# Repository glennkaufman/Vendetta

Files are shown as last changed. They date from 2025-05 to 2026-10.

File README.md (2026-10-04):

# Vendetta Toolhead Assembly Guide

Welcome to the official assembly guide for the **Vendetta Toolhead**—designed to deliver fully functional ability to use your V400 with Box Turtle!
Fully fuctional toolhead cutting, filament sensors, lighting, Canbus or USB, CPAP or stock cooling.

---

## 🔧 Tools & Materials Required

* Original V400 effector for base parts
* Soldering iron (for inserts)
* [BOM Hardware](assembly/BOM.md)
* Your full set of Vendetta STLs

---

## 📦 Bill of Materials

*All STL files are organized in subfolders within `/models/STLs/`*
### [*Hardware BOM*](assembly/BOM.md)

### Main Body

* [`main_body_front_enable_supports.stl`](models/STLs/main_body_front/main_body_front_enable_supports.stl)
* [`main_body_rear.stl`](models/STLs/main_body_rear/main_body_rear.stl)

### Cutter Arm

* [`cutter_arm.stl`](models/STLs/cutter_arm/cutter_arm.stl)
* [`cutter_arm_button.stl`](models/STLs/cutter_arm/cutter_arm_button.stl)
* [`cutter_arm_button_v2.stl`](models/STLs/cutter_arm/cutter_arm_button_v2.stl)
* [`cutter_arm_mount_cutter_pin.stl`](models/STLs/cutter_arm/cutter_arm_mount_cutter_pin.stl)
* [`cutter_arm_mount_cutter_pin_long.stl`](models/STLs/cutter_arm/cutter_arm_mount_cutter_pin_long.stl)

### Shroud

* [`shroud.stl`](models/STLs/shroud/shroud.stl)
* [`shroud_fan.stl`](models/STLs/shroud/shroud_fan.stl)
* [`shroud_logo.stl`](models/STLs/shroud/shroud_logo.stl)

### CPAP Adapter

* [`cpap_upper.stl`](models/STLs/cpap/cpap_upper.stl)
* [`cpap_mid_left.stl`](models/STLs/cpap/cpap_mid_left.stl)
* [`cpap_mid_right.stl`](models/STLs/cpap/cpap_mid_right.stl)
* [`cpap_low_left.stl`](models/STLs/cpap/cpap_low_left.stl)
* [`cpap_low_right.stl`](models/STLs/cpap/cpap_low_right.stl)

### Idler

* [`idler_with_supports.stl`](models/STLs/idler/idler_with_supports.stl)

### Fan Duct Covers

* [`Fan_Duct_Covers.stl`](models/STLs/fan_duct_covers/Fan_Duct_Covers.stl)

### Misc Add-ons

* [`rear_pillar_brush_indexer.stl`](models/STLs/misc_addons/rear_pillar_brush_indexer.stl)

---

## 🧠 Assembly Overview

The Vendetta Toolhead is a modular, high-performance design tailored for Box Turtle Automated Filament Changer.

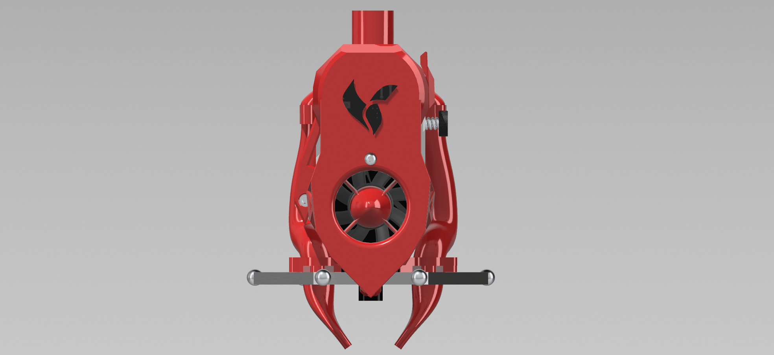
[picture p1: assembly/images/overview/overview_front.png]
Overview Front

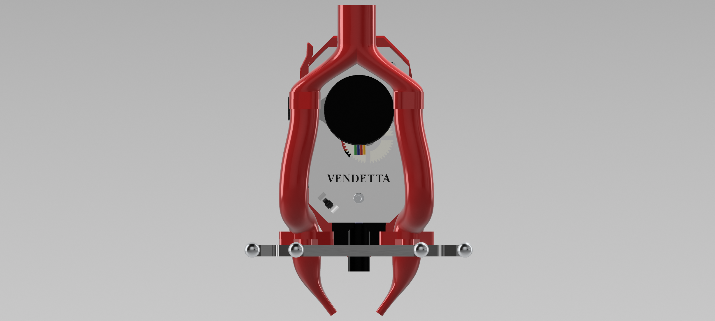
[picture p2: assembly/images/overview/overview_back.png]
Overview Back

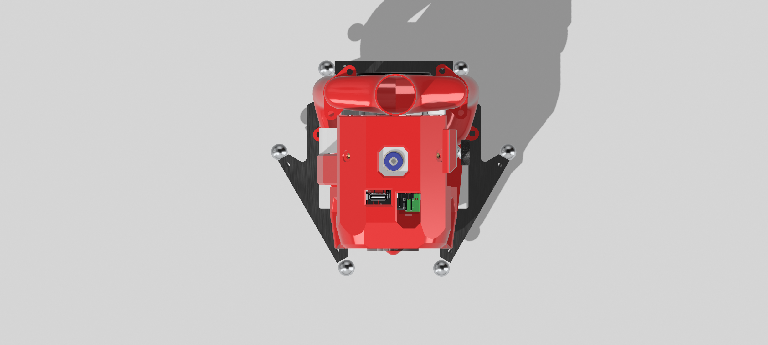
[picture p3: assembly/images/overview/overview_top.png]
Overview Perspective


---

## 🧱 Main Body (Front)

Secures to the effector via the heatsink. Houses cutting blade, filament sensor, and EBB42.

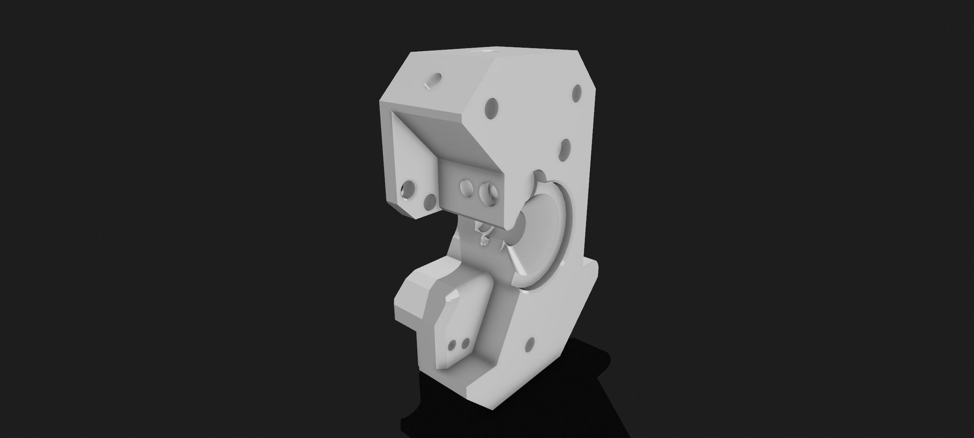
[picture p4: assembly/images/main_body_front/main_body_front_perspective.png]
Main Body Perspective


---

## 🧱 Main Body (Rear)

Secures to the main body front. Mounts the stock stepper for the extruder.

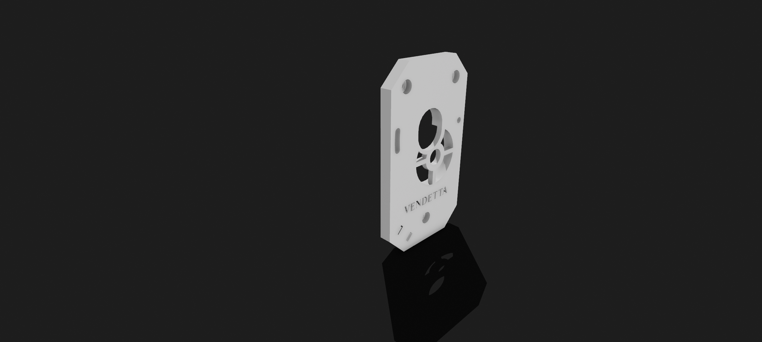
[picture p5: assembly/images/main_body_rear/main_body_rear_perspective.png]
Main Body Perspective


---

## ⚙️ Cutter Arm

Used for filament cutting. Options for cutting your own chisel blades or purchasing bambu cutter blades.

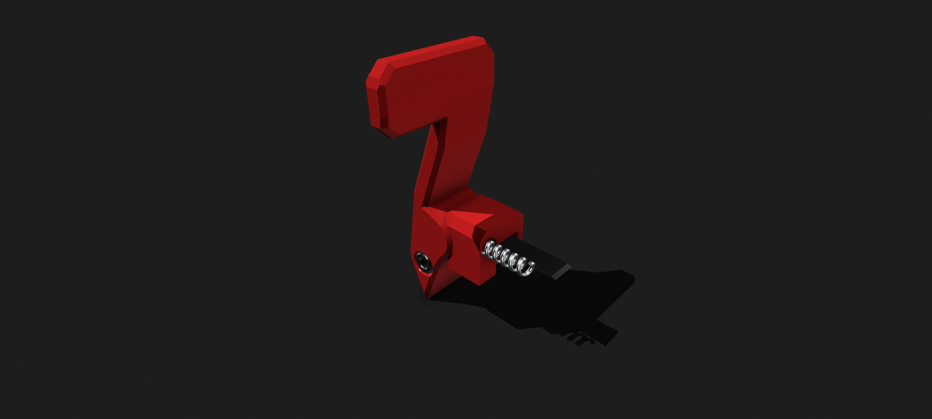
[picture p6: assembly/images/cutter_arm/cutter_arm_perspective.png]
Cutter Arm Perspective


---

## 🌬️ Shroud

Ability to integrate Knomiv2 or strictly run heatbreak fan with nose cone.

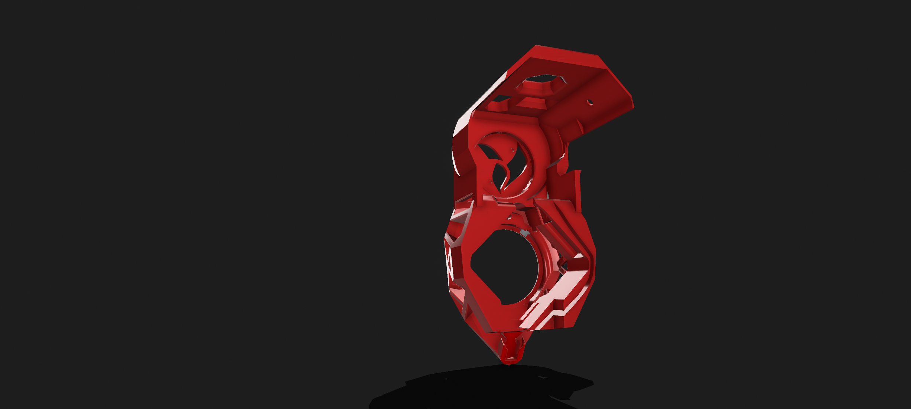
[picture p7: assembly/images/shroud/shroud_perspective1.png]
Shroud Perspective1

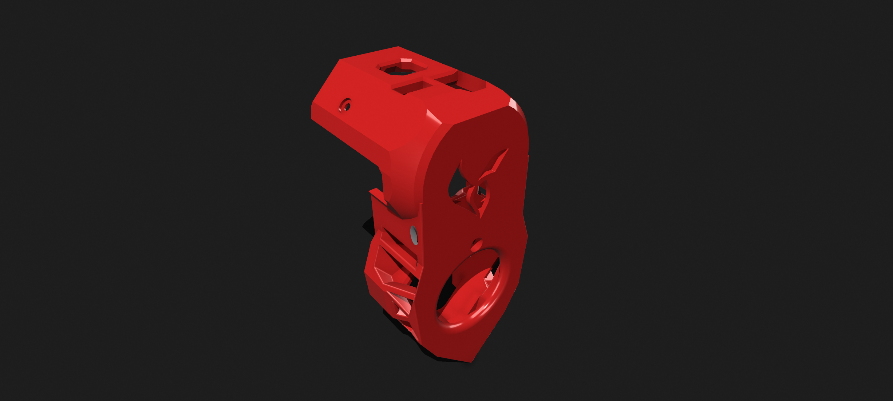
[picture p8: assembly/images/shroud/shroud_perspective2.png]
Shroud Perspective2


---

## 🫁 CPAP Adapter

Optional component for integrating an external CPAP high-flow fan.

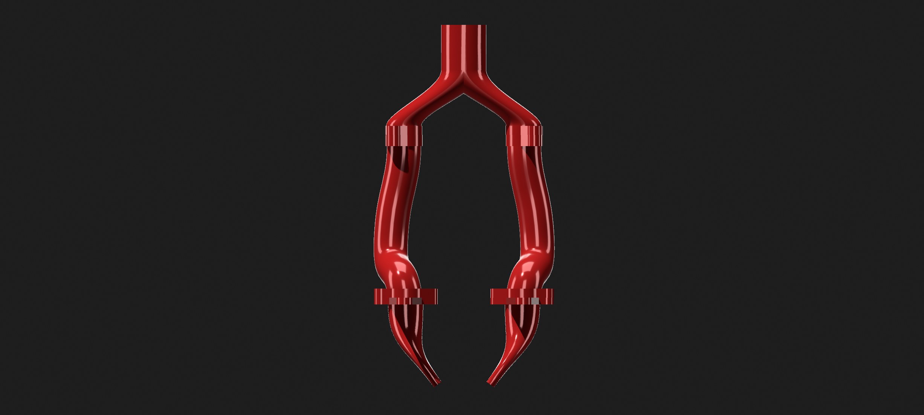
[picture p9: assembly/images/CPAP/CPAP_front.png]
CPAP Front

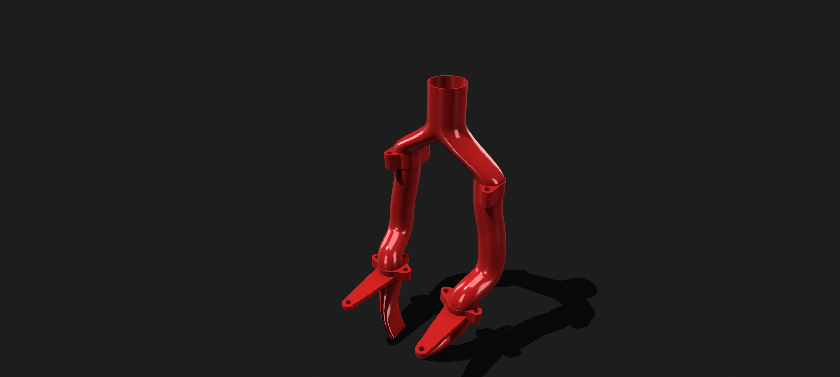
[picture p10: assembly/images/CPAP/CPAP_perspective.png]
CPAP Perspective


---

## 🛞 Idler

Extruder tension arm for filament path.

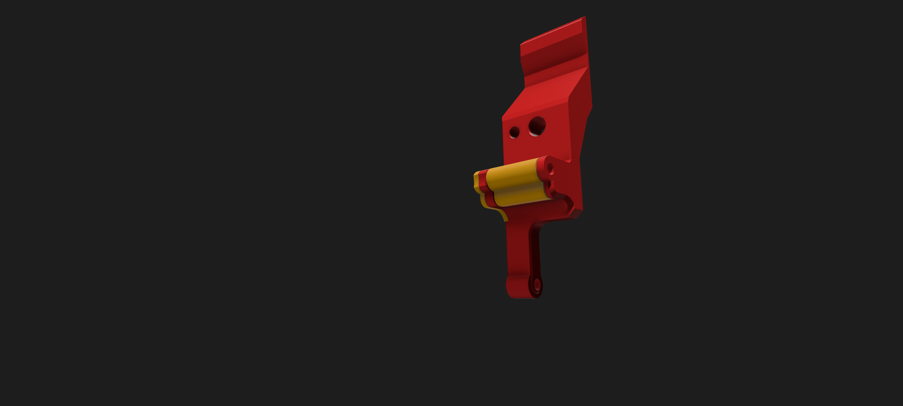
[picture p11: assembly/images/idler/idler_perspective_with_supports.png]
Idler Perspective


---

## ✅ Final Assembly Checklist

* [ ] All bolts torqued
* [ ] Threadlocker applied where needed
* [ ] Fan and CPAP tested
* [ ] Belt alignment verified
* [ ] Hotend wired and verified

---

## Firmware Configuration

All firmware configuration files are organized under the [`firmware/config_files/`](firmware/config_files) directory, sorted by hardware and use case. These settings are tailored specifically for the Vendetta tool head and its supporting components.

- **Box Turtle Settings**  
  Configuration optimized for the Box Turtle mod—ensuring smooth integration and reliable performance on supported machines. (`AFC*.cfg` files in `firmware/config_files/`)

- **Octopus Pro v1.1 (H723)**  
  Dedicated configuration files for the BigTreeTech Octopus Pro v1.1 (H723) board. These files are pre-tuned for compatibility and performance. (`firmware/config_files/octopus_pro_and_vendetta_toolhead/`)

- **Vendetta Tool Head**  
  Custom settings specifically for the Vendetta tool head. Includes pin mappings, thermal tuning, and motion tweaks to get the most out of your hardware.

> **Note:** The sample configs are for reference only. They were tested with Klipper v0.13.x (my printer runs v0.13.0-786 as of Oct 2026). Pressure advance, input shaper, and the AFC bowden length (`afc_bowden_length`) and `tool_stn` / `tool_stn_unload` values are specific to my printer and must be tuned for yours.

---

## [📹 Assembly Videos](assembly/Videos.md)

*In Production to YouTube — [YouTube](https://youtube.com/playlist?list=PLWgEg1ho19xm_LMkO39CTWQdfH5PHcdP_&si=Ss74mZV-d5u0i4Tc)*

---

## 🧠 Notes

* For firmware configurations, PID tuning, and offsets, refer to your printer’s mainboard documentation.
* Contributions welcome. Submit pull requests or file issues as needed.

---

## 🔗 License

MIT License. Build, remix, and share—with attribution.

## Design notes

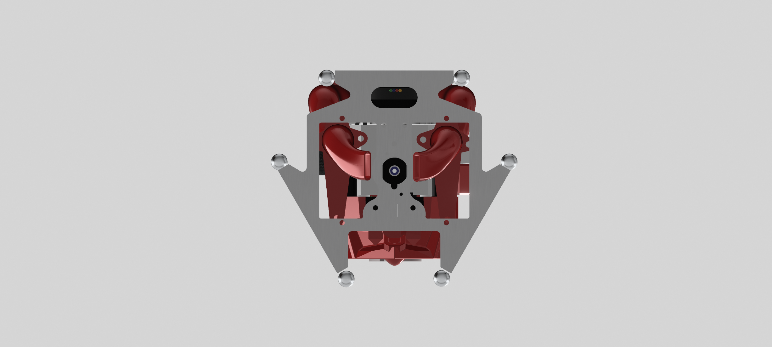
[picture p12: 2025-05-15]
assembly/images/overview/overview_bottom.png

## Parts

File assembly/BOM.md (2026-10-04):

# Bill of Materials (BOM)

| | | BOM | | | | |
|:---|:---|:---|:---|:---|:---|:---|
| Number | Description | Quantity | Link | Price | REQ/OPT | |
| 1 | BIGTREETECH EBB42 CAN Bus with MAX31865 Adapter Board | 1 | [Link](https://amzn.to/46TVVoy) | $ 23.99 | REQ | |
| 2 | BIGTREETECH KNOMI 2 | 1 | [Link](https://amzn.to/48OWNxd) | $ 31.99 | OPT | Not required if using cone in Vendetta hotend |
| 3 | GDSTIME 2Pcs 40mm Fan 24V, Dual Ball Bearing 40x40x10mm | 1 | [Link](https://amzn.to/42QUrdJ) | $ 10.39 | OPT | Not required if using original heatsink fan |
| 4 | BIGTREETECH Octopus Pro v1.1 (H723) Control Board 32Bit Silent Motherboard | 1 | [Link](https://amzn.to/4h46FW6) | $ 43.19 | OPT | Not required if using original control board |
| 5 | BIGTREETECH Universal Turbo Kit 24V Brushless Centrifugal Air Blower | 1 | [Link](https://amzn.to/3VUjiJy) | $ 60.79 | OPT | Not required if using stock parts cooling fans |
| 6 | MR63ZZ Miniature Deep Groove Ball Bearings,Pre-Lubricated & High RPM Support - - 3x6x2.5mm | 3 | [Link](https://amzn.to/4mRJxLK) | $ 10.99 | REQ | |
| 7 | Bamboo lab 3PCS Filament Cutter Blade | 1 | [Link](https://amzn.to/4nCCKXj) | $ 9.99  | REQ | |
| 8 | M3 Heat Inserts M3 x D5 x L4 Brass Threaded Inserts | 14 | [Link](https://amzn.to/4mXmqj5) | $ 9.99  | REQ | |
| 9 | WS2812B RGB LED Rings 7 Bits 5050 Lamp Light with Integrated Drivers | 1 | [Link](https://amzn.to/4o2e1vs) | $ 15.99 | REQ | |
| 10 | WS2812B Addressable 5050 Smart RGB LED Pixel Light on Black Heat Sink PCB Board 5V DC | 1 | [Link](https://amzn.to/432MHVP) | $ 14.99 | REQ | |
| 11 | Capricorn Teflon Tube PTFE Bowden Tubing 1.75mm Filament, Low Friction | 1 | [Link](https://amzn.to/48lsAWq) | $ 11.49 | REQ | |
| 12 | BMG Extruder kit w MR85 bearings | 1 | [Link](https://amzn.to/4o8dMPC) | $ 14.99 | OPT | Optional, but includes MR85 bearings. No need to purchase separate bearings below |
| 13 | MR85-2RS Deep Groove Ball Bearings 5mm Inner Dia 8mm OD 2.5mm Bore Double Sealed Chrome Steel Z2 | 2 | [Link](https://amzn.to/4oak5Cm) | $ 8.19  | REQ | Required if using stock V400 extruder gears |
| 14 | Omron D2HW-C201H | 1 | [Link](https://mou.sr/3ILoFrw) | $ 2.35  | REQ | |
| 15 | M3x25 BHCS | 1 | | | | |
| 16 | M3x20 SHCS | 2 | | | | |
| 17 | M3x16 SHCS | 2 | | | | Can use stock hardware |
| 18 | M3x8 BHCS | 4 | | | | |
| 19 | M3x6 BHCS | 9 | | | | |
| 20 | ECAS Bowden Collet | 1 | | | | |
| 21 | 4mmODx20 .5 Spring | 1 | | | | |

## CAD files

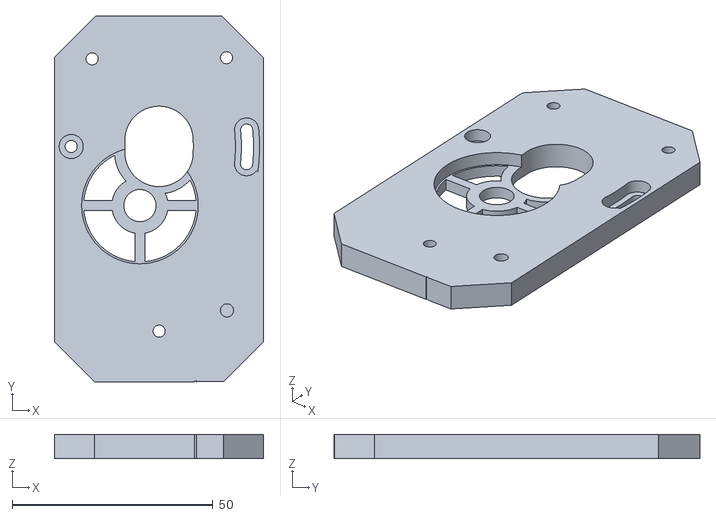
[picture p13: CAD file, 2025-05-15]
models/STLs/main_body_rear/main_body_rear.stl
52.0 x 91.0 x 6.00

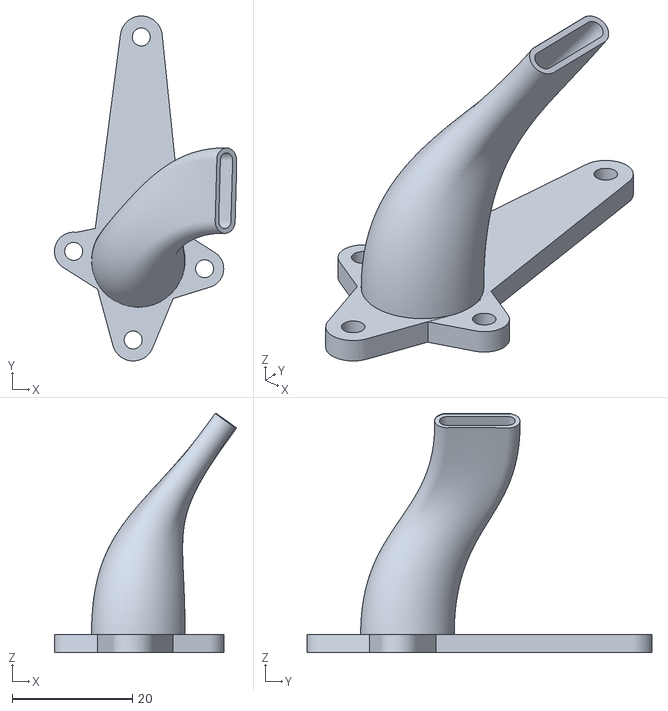
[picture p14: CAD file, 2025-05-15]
models/STLs/cpap/cpap_low_left.stl
30.3 x 57.5 x 39.9

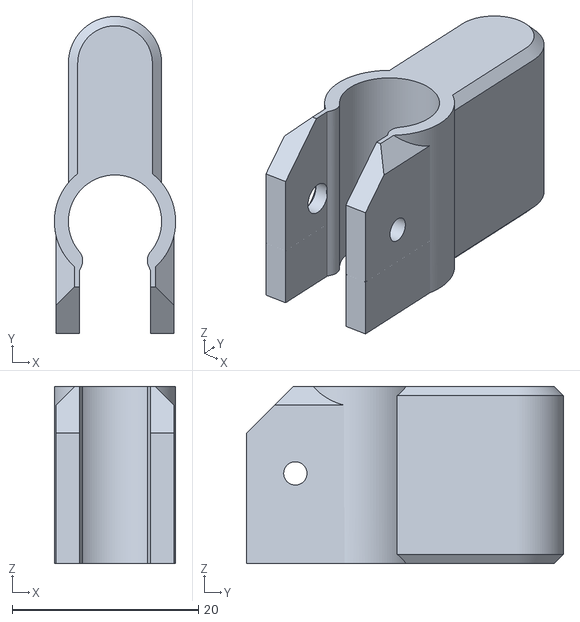
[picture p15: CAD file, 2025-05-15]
models/STLs/cutter_arm/cutter_arm_mount_cutter_pin_long.stl
13.0 x 34.0 x 19.0

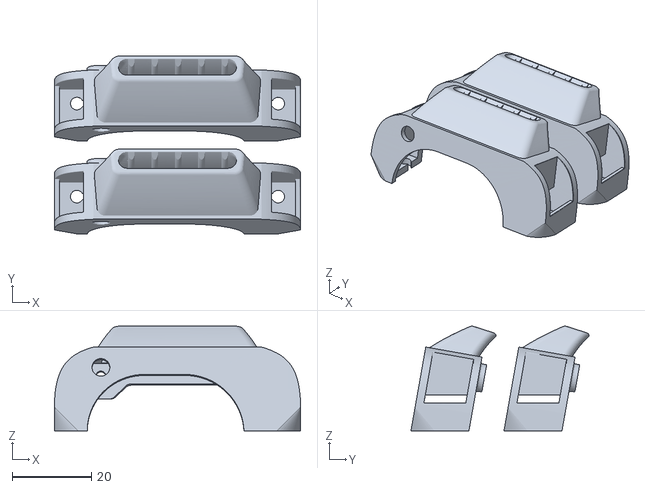
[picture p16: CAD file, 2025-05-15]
models/STLs/fan_duct_covers/Fan_Duct_Covers.stl
62.0 x 44.9 x 26.4

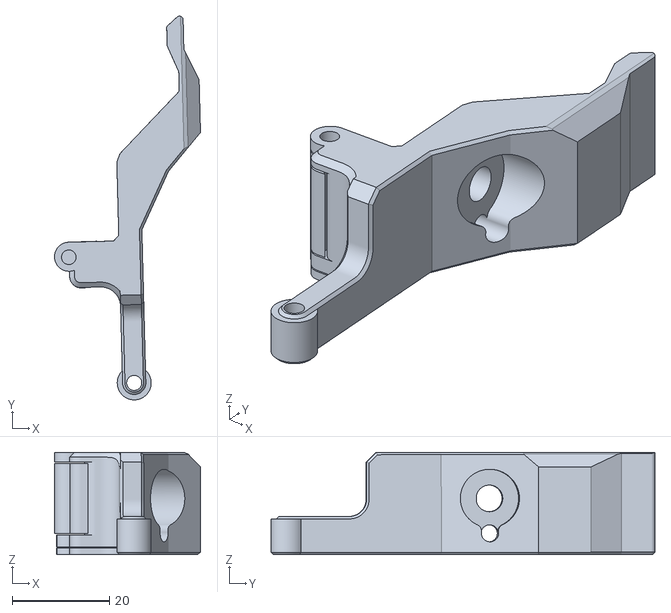
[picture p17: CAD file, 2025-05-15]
models/STLs/idler/idler_with_supports.stl
30.1 x 79.1 x 21.1

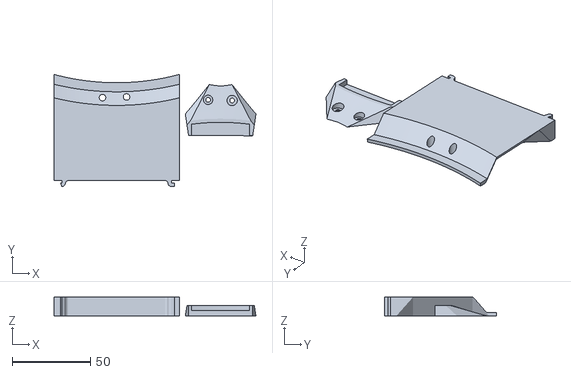
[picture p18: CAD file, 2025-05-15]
models/STLs/misc_addons/rear_pillar_brush_indexer.stl
129.1 x 71.7 x 11.9

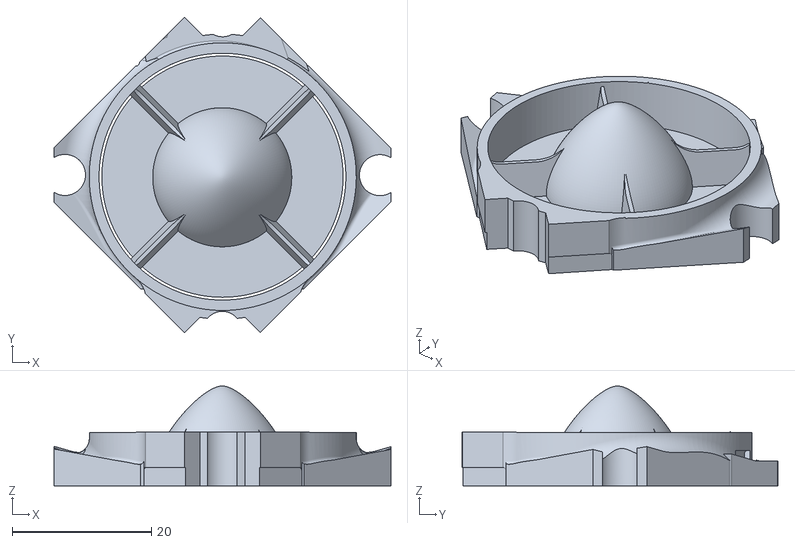
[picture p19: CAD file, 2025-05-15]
models/STLs/shroud/shroud_fan.stl
48.5 x 45.4 x 14.4

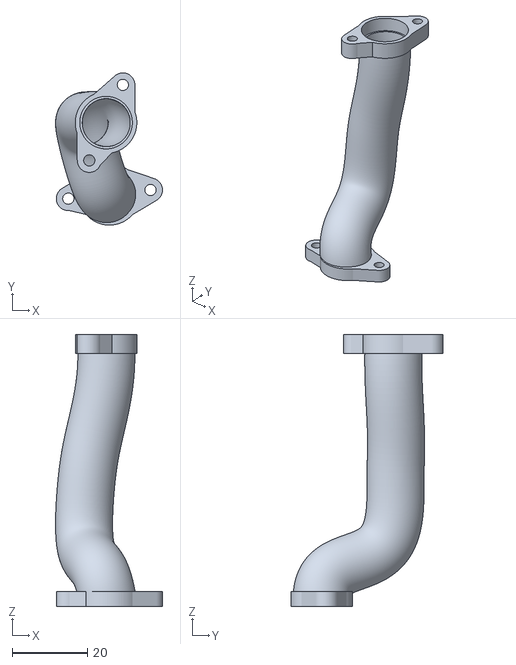
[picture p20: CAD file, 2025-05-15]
models/STLs/cpap/cpap_mid_left.stl
28.5 x 40.5 x 72.4

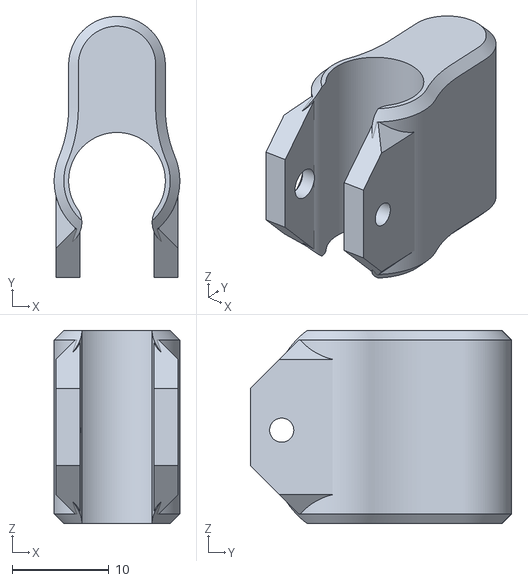
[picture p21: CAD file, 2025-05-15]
models/STLs/cutter_arm/cutter_arm_mount_cutter_pin.stl
13.0 x 27.0 x 20.0

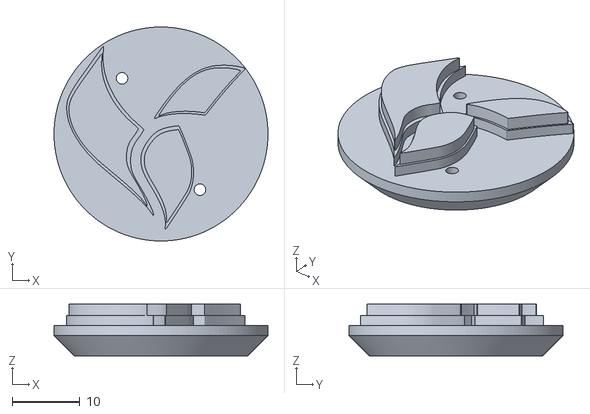
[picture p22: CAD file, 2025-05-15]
models/STLs/shroud/shroud_logo.stl
31.5 x 31.5 x 7.64

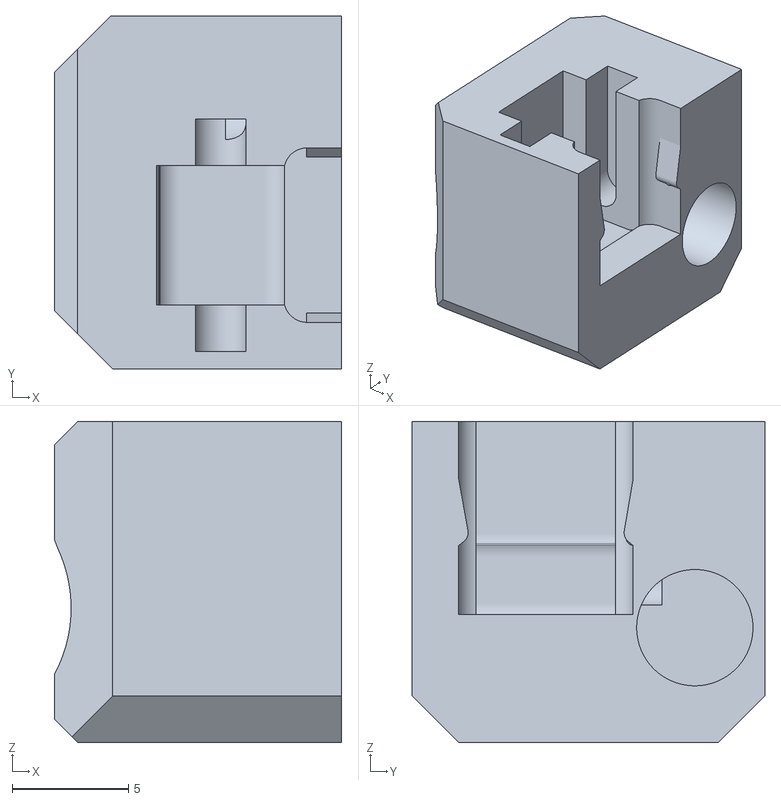
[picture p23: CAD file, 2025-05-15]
models/STLs/cutter_arm/cutter_arm_button.stl
12.3 x 15.2 x 13.8

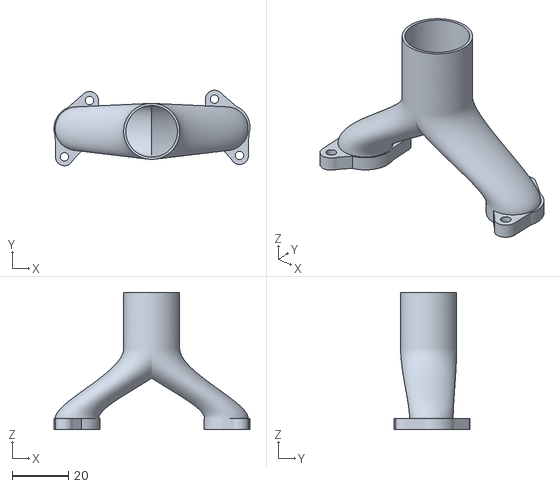
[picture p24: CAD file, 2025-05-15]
models/STLs/cpap/cpap_upper.stl
69.9 x 27.0 x 49.0

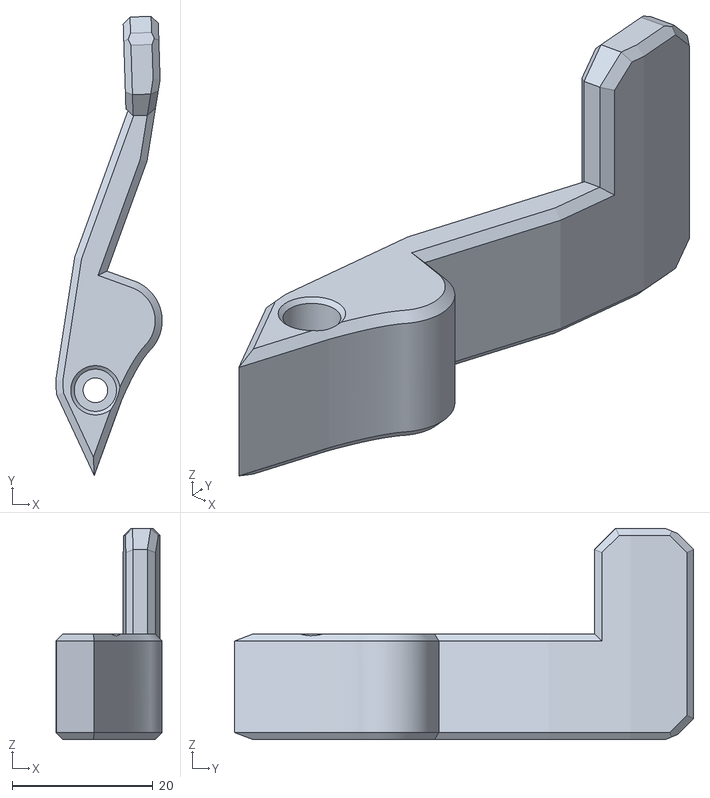
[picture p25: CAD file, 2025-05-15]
models/STLs/cutter_arm/cutter_arm.stl
15.1 x 65.3 x 30.0

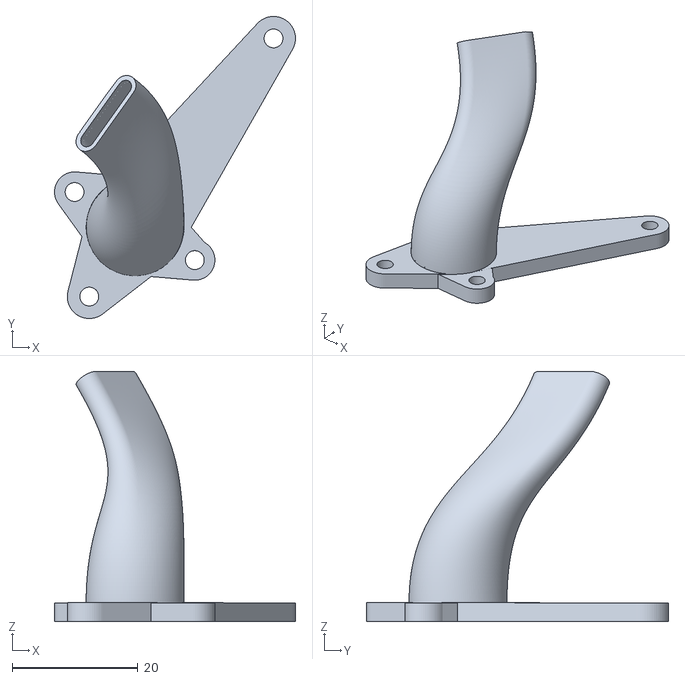
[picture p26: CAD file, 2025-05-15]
models/STLs/cpap/cpap_low_right.stl
38.4 x 48.1 x 39.9

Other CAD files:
models/STLs/main_body_front/main_body_front_enable_supports.3mf
models/STLs/cpap/cpap_mid_right.stl
models/STLs/cutter_arm/cutter_arm_button_v2.stl
models/STLs/main_body_front/main_body_front_enable_supports.stl

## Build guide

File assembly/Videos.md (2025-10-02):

## 📹 Assembly Videos

### Vendetta Parts Print (https://www.youtube.com/watch?v=nWyVzOlXdS0)  
*Vendetta Parts Print* — 6:20

### Vendetta - Supports Removal (https://www.youtube.com/watch?v=ZrVvXxl8cqo)  
*Vendetta - Supports Removal* — 8:28

### Vendetta - Heatset Inserts Installation (https://www.youtube.com/watch?v=ajmu_imUpPU)  
*Vendetta - Heatset Inserts Installation* — 9:12

### Vendetta - Parts Assembly (https://www.youtube.com/watch?v=J0I8exbBQgA)
*Vendetta - Parts Assembly* — 1:19:37

---

### 🎥 **Full Playlist:** [Vendetta Toolhead Assembly on YouTube](https://www.youtube.com/playlist?list=PLWgEg1ho19xm_LMkO39CTWQdfH5PHcdP_)

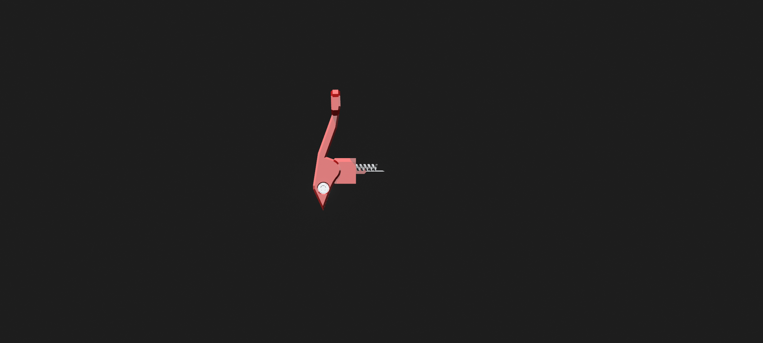
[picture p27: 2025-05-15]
assembly/images/cutter_arm/cutter_arm_front.png

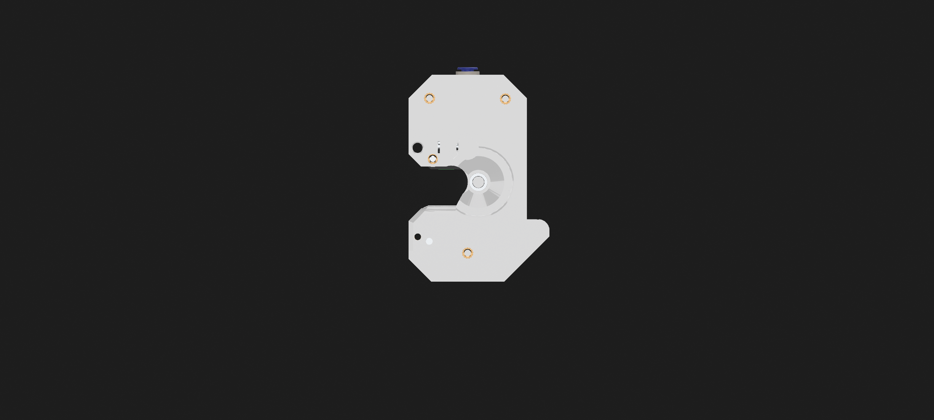
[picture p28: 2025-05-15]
assembly/images/main_body_front/main_body_front_back.png

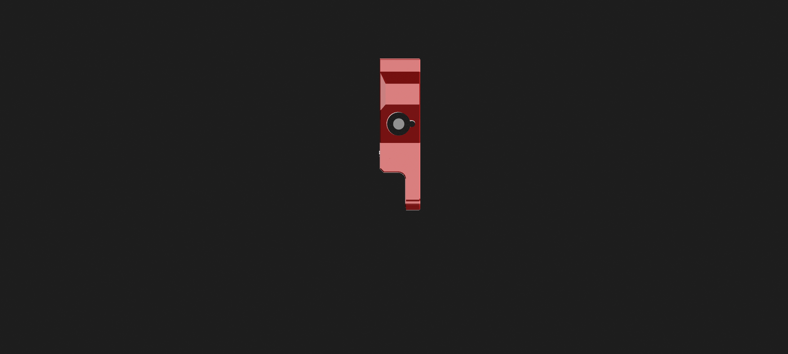
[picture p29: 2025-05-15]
assembly/images/idler/idler_right.png

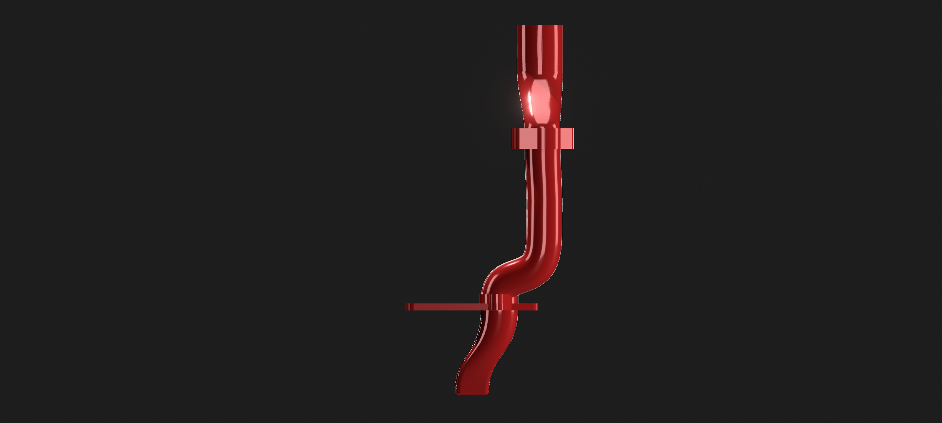
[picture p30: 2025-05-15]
assembly/images/CPAP/CPAP_right.png

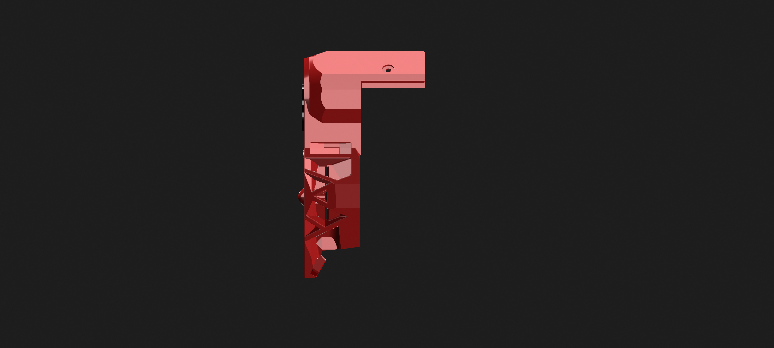
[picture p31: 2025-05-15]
assembly/images/shroud/shroud_right.png

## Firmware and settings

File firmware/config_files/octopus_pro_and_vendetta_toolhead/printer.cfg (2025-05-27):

#   _____             __ _                       _   _                
#  / ____|           / _(_)                     | | (_)                
# | |     ___  _ __ | |_ _  __ _ _   _ _ __ __ _| |_ _  ___  _ __  ___ 
# | |    / _ \| '_ \|  _| |/ _` | | | | '__/ _` | __| |/ _ \| '_ \/ __|
# | |___| (_) | | | | | | | (_| | |_| | | | (_| | |_| | (_) | | | \__ \
#  \_____\___/|_| |_|_| |_|\__, |\__,_|_|  \__,_|\__|_|\___/|_| |_|___/
#                           __/ |                                      
#                          |___/    
#
# Klipper Configurations - Flsun V400


########################################
# Firmware Settings
########################################

# This file contains common pin mappings for the BigTreeTech Octopus
# Pro v1.1 board.

# Important! Do not use this config with an Octopus Pro v1.0 board nor
# non-Pro board.

# To use this config, during "make menuconfig", select "Enable
# low-level configuration options", select the STM32H723
# micro-controller, select a "128KiB bootloader", and select a "25Mhz
# crystal".

# See docs/Config_Reference.md for a description of parameters.

########################################
# Editable Settings
########################################

# Notes: Some settings can be enabled or disabled by removing or adding the '#' symbol
#
# PID (pid_Kp, pid_Ki, pid_Kd) --> [extruder] and [heater_bed] sections
# E-Steps Extruder (rotation_distance) --> [extruder] section --> <rotation_distance> = <full_steps_per_rotation> * <microsteps> / <steps_per_mm>
# Pressure Advance (pressure_advance) --> [extruder] section -- See: https://www.klipper3d.org/Pressure_Advance.html
# Firmware Retraction --> [firmware_retraction] section -- Requires "Klipper Settings Plugin" for Cura -- See: https://github.com/jjgraphix/KlipperSettingsPlugin

########################################
# Included Files
########################################

#[include macros.cfg]    #Enable to use macros file
#[include timelapse.cfg]  #Enable if you want to use Timelapse
#[include btt-hbb.cfg]
#[include led-effects.cfg]
#[include vendetta_led.cfg]
#[include AFC/*.cfg]
#[include BTKS_Macros.cfg]

########################################
# Printer Settings
########################################

[printer]
kinematics: delta
max_velocity: 600
max_accel: 3500
minimum_cruise_ratio: 0.5
square_corner_velocity: 6
max_z_velocity: 300
max_z_accel: 1500
minimum_z_position: -5
print_radius: 152
#delta_radius: 161.75

########################################
# MCU Settings
########################################

[mcu]        #Select serial or canbus
#serial: 
#canbus_uuid: 
#canbus_interface: can0
[mcu EBBCan]  #Select serial or canbus
#serial: 
#canbus_uuid: 
#canbus_interface: can0

[temperature_sensor Motherboard]
sensor_type: temperature_mcu
min_temp: 20
max_temp: 80

[temperature_sensor EBB]
sensor_type: temperature_mcu
sensor_mcu: EBBCan
min_temp: 20
max_temp: 80

[temperature_sensor RaspberryPi]
sensor_type: temperature_host
min_temp: 10
max_temp: 80 

########################################
# X Stepper Motor & Driver Settings
########################################

# Stepper a
[stepper_a]
step_pin: PF13
dir_pin: PF12
enable_pin: !PF14
microsteps: 64
rotation_distance: 40
endstop_pin: PG6 #STOP0
homing_speed: 50
homing_retract_dist: 5.0
homing_retract_speed: 10
#angle: 210
#position_endstop: 415.0
#arm_length = 345.0

[tmc2209 stepper_a]
uart_pin: PC4
diag_pin: PG6 #STOP0
run_current: 1.500
sense_resistor = .110
interpolate: false
stealthchop_threshold: 0

#[autotune_tmc stepper_a]  # Enable if Klipper TMC Autotune is used
#motor: flsun-v400-42
#tuning_goal: performance

[endstop_phase stepper_a]
endstop_align_zero: False

########################################
# Y Stepper Motor & Driver Settings
########################################

# Stepper b
[stepper_b]
step_pin: PG0
dir_pin: PG1
enable_pin: !PF15
microsteps: 64
rotation_distance: 40
endstop_pin: PG9
#angle: 330

[tmc2209 stepper_b]
uart_pin: PD11
diag_pin: PG9
run_current: 1.500
sense_resistor = .110
interpolate: false
stealthchop_threshold: 0

#[autotune_tmc stepper_b]  # Enable if Klipper TMC Autotune is used
#motor: flsun-v400-42
#tuning_goal: performance

[endstop_phase stepper_b]
endstop_align_zero: False

########################################
# Z Stepper Motor & Driver Settings
########################################

# Stepper c
[stepper_c]
step_pin: PF11
dir_pin: PG3
enable_pin: !PG5
microsteps: 64
rotation_distance: 40
endstop_pin: PG10
#angle: 90

[tmc2209 stepper_c]
uart_pin: PC6
diag_pin: PG10
run_current: 1.500
sense_resistor = .110
interpolate: false
stealthchop_threshold: 0

#[autotune_tmc stepper_c]  # Enable if Klipper TMC Autotune is used
#motor: flsun-v400-42
#tuning_goal: performance

[endstop_phase stepper_c]
endstop_align_zero: False 

########################################
# Extra Stepper Motor & Driver Settings
########################################

# Driver3
# The Octopus only has 4 heater outputs which leaves an extra stepper
# This can be used for a second Z stepper, dual_carriage, extruder co-stepper,
# or other accesory such as an MMU
#[stepper_]
#step_pin: PG4
#dir_pin: PC1
#enable_pin: !PA2
#endstop_pin: PG11
#...

########################################
# Extruder & Driver Settings
########################################
#SETTINGS BELOW ARE FOR VENDETTA TOOLHEAD

[extruder]
step_pin: EBBCan: PD0
dir_pin: !EBBCan: PD1
enable_pin: !EBBCan: PD2
microsteps: 16
rotation_distance: 4.500
nozzle_diameter: 0.400
filament_diameter: 1.750
max_extrude_cross_section: 50
max_extrude_only_distance: 1000
pressure_advance: 0.02
pressure_advance_smooth_time: 0.040
heater_pin: EBBCan: PB13
sensor_type: EPCOS 100K B57560G104F
sensor_pin: EBBCan: PA3
#control: pid_v
#pid_Kp=15.752
#pid_Ki=0.908
#pid_Kd=68.331
min_temp: 10
max_temp: 300

[tmc2209 extruder]
uart_pin: EBBCan: PA15
run_current: 0.8
sense_resistor = .110
interpolate: True
stealthchop_threshold: 999999

[heater_fan hotend_fan]
pin: EBBCan: PA0
heater: extruder
heater_temp: 50.0

# Driver4
#[extruder]
#step_pin: PF9
#dir_pin: !PF10
#enable_pin: !PG2
#heater_pin: PA0 # HE0
#sensor_pin:  PF4 # T0
#...

# Driver5
#[extruder1]
#step_pin: PC13
#dir_pin: PF0
#enable_pin: !PF1
#heater_pin: PA3 # HE1
#sensor_pin: PF5 # T1
#...

# Driver6
#[extruder2]
#step_pin: PE2
#dir_pin: PE3
#enable_pin: !PD4
#heater_pin: PB0 # HE2
#sensor_pin: PF6 # T2
#...

# Driver7
#[extruder3]
#step_pin: PE6
#dir_pin: PA14
#enable_pin: !PE0
#heater_pin: PB11 # HE3
#sensor_pin: PF7 # T3
#...

########################################
# Delta Calibration & Mesh Settings
########################################

[delta_calibrate]
radius: 148
horizontal_move_z: 25
speed: 50

[bed_mesh]
speed: 100
horizontal_move_z: 30
mesh_radius: 148
mesh_origin: 0,0
mesh_pps: 4,4
round_probe_count: 9
algorithm: bicubic
bicubic_tension: 0.1
move_check_distance: 5
zero_reference_position: 0,0
fade_start: 1
fade_end: 30 

########################################
# Temperature Controls
########################################

[verify_heater extruder]
max_error: 160
heating_gain: 1

[verify_heater heater_bed]
max_error: 120
heating_gain: 1

########################################
# Heating
########################################

[heater_bed]
heater_pin: PA1 #BED-OUT
sensor_pin: PF3 #TB
sensor_type: EPCOS 100K B57560G104F
min_temp: 10
max_temp: 120
#control = pid_v
#pid_kp = 64.044
#pid_ki = 3.812
#pid_kd = 268.984

########################################
# Firmware Retraction Settings
########################################

[firmware_retraction]
retract_length: 0.2
retract_speed: 50
unretract_extra_length: 0.00
unretract_speed: 50

########################################
# Input Shaper Settings
########################################

[adxl345]    #ADXL1345 ON VENDETTA TOOLHEAD
cs_pin: EBBCan: PB12
spi_software_sclk_pin: EBBCan: PB10
spi_software_mosi_pin: EBBCan: PB11
spi_software_miso_pin: EBBCan: PB2
axes_map: x,y,z

[input_shaper]
shaper_freq_x: 42.0
shaper_type_x = ei
shaper_freq_y: 56.2
shaper_type_y = 2hump_ei
damping_ratio_x: 0.183
damping_ratio_y: 0.171

[resonance_tester]
probe_points:0, 0, 200
accel_chip: adxl345
max_smoothing:0.5
min_freq: 5
max_freq: 133.33
accel_per_hz: 75
hz_per_sec: 1

[idle_timeout]
timeout: 10800

[save_variables]
filename: ~/printer_data/config/variables.cfg

[virtual_sdcard]
path: ~/printer_data/gcodes

[display_status]

[pause_resume]

[respond]

########################################
# LED Settings
########################################

[neopixel vendetta_leds]
pin: EBBCan:PD3
chain_count: 8
#   The number of Neopixel chips that are "daisy chained" to the
#   provided pin. 1-7 in the logo and 8 at the lower shroud for nozzle.
color_order: GRB
#   Set the pixel order required by the LED hardware. Options are GRB,
#   RGB, GRBW, or RGBW. The default is GRB.
initial_RED: 0
initial_GREEN: 0
initial_BLUE: 0
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

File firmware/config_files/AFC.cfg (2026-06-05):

[AFC]
VarFile: /home/glenn/printer_data/config/AFC/AFC.var   # Path to the variables file for AFC configuration.

#--=================================================================================-
#------- Speed ----------------------------------------------------------------------
#--=================================================================================-
long_moves_speed: 150           # mm/s. Default value is 150mm/s.
long_moves_accel: 250           # mm/s². Default value is 250mm/s².
short_moves_speed: 50           # mm/s. Default value is 50mm/s.
short_moves_accel: 300          # mm/s². Default value is 300mm/s².
short_move_dis: 10              # Move distance for failsafe moves. Default is 10mm.

#global_print_current: 0.6       # Uncomment to set stepper motors to a lower current while printing
                                # This value can also be set per stepper with print_current: 0.6
enable_sensors_in_gui: True     # Uncomment to show all sensor switches as filament sensors in mainsail/fluidd gui
                                # this can also be set at individual levels in your config file
default_material_temps: default: 235, PLA:210, PETG:235, ABS:235, ASA:235 # Default temperature to set extruder when loading/unloading lanes.
                                                  # Material needs to be either manually set or uses material from spoolman if extruder temp is not
                                                  # set in spoolman. Follow current format to add more
common_density_values: PLA:1.24, PETG:1.23, ABS:1.04, ASA:1.07 # Generic default density values.  Follow current format to add more
default_material_type: ASA     # Default material type to assign to a spool once loaded into a lane

load_to_hub: True               # Fast loads filament to hub when inserted, set to False to disable. This is a global setting and can be overridden at AFC_stepper
#moonraker_port: 7125            # Port to connect to when interacting with moonraker. Used when there are multiple moonraker/klipper instances on a single host

assisted_unload: True           # If True, the unload retract is assisted to prevent loose windings, especially on full spools. This can prevent loops from slipping off the spool. This is a global setting and can be overridden at the unit and stepper level.
#pause_when_bypass_active: True  # When True AFC pauses print when change tool is called and bypass is loaded
#unload_on_runout: True          # When True AFC will unload lane and then pause when runout is triggered and spool to swap to is not set(infinite spool)
#print_short_stats: True          # Set to true to print AFC_STATS in short form instead of wide form, printing short form is better for consoles that are small in width
#debug: True                     # Setting to True turns on more debugging to show on console

#--=================================================================================-
#------- TRSYNC Values --------------------------------------------------------------
#--=================================================================================-
#trsync_update: True           # Uncomment this value to update Klipper's trsync value automatically
#trsync_timeout: 0.05          # Uncomment this value if timeout needs to be greater than the default of 0.05
#trsync_single_timeout: 0.250  # Uncomment this value if single_timeout needs to be greater than the default of 0.250

#--=================================================================================-
#------- Pause/Resume ---------------------------------------------------------------
#--=================================================================================-
z_hop: 5                        # Height to move up before and after a tool change completes
resume_speed: 120               # Speed mm/s of resume move. Set to 0 to use gcode speed
resume_z_speed: 30              # Speed mm/s of resume move in Z. Set to 0 to use gcode speed
error_timeout: 36000            # Time in seconds to pause when an error is detected.
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

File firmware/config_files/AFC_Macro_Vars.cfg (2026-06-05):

[include macros/*.cfg]

#--=================================================================================-
#------- Global ---------------------------------------------------------------------
#--=================================================================================-
[gcode_macro _AFC_GLOBAL_VARS]
description: Global variables used in multiple macros
gcode: # Leave Empty

# Set this to match your AFC_stepper base naming in AFC_Hardware.cfg
variable_stepper_name             : 'lane'    # [AFC_stepper lane1] [AFC_stepper lane2]...

variable_travel_speed             : 200      # Speed mm/s
variable_z_travel_speed           : 50        # Speed mm/s
variable_accel                    : 2000      # Move accel for all macro moves
variable_disable_skew_correction  : False      # When True macros will disable and re-enable skew correction while performing kinematic actions, useful if you took your measurements before loading your skew profiles which may limit where the toolhead can go during print.
variable_verbose                  : 1         # Console Output for macros
                                              #  0 - None
                                              #  1 - Limited
                                              #  2 - All


#--=================================================================================-
#------- Cut -----------------------------------------------------------------------
#--=================================================================================-
[gcode_macro _AFC_CUT_TIP_VARS]
description: Toolhead tip cutting macro configuration variables
gcode: # Leave empty

# This should be the position of the toolhead where the cutter arm just
# lightly touches the depressor pin
variable_pin_loc_xy               : -100, 0    # x,y coordinates of depressor pin

# Accel during cut. This will overwrite the global accel for this macro. Set to 0 to use global accel
variable_cut_accel                : 0

# Direction to make the cut move (left, right, front, back)
variable_cut_direction            : "left"

# This distance is used to move toolhead to cut filament
# and to create a small safety distance that aids in generating momentum
variable_pin_park_dist            : 10.0       # Distance in mm

# Position of the toolhead when the cutter is fully compressed.
# Distance the toolhead needs to travel to compress the cutter arm.
# To calculate this distance start at the pin_loc_xy position and move
# your toolhead till the cutter arm is completely compressed. Take 0.5mm off this distance
# as a buffer. 
# Ex pin_loc_x : 9, 310  fully compressed at 0, 310 set cut_move_dist to 8.5
variable_cut_move_dist            : 52       # Distance in mm

# Speed related settings for tip cutting
# Note that if the cut speed is too fast, the steppers can lose steps.
# Therefore, for a cut:
# - We first make a fast move to accumulate some momentum and get the cut
#   blade to the initial contact with the filament
# - We then make a slow move for the actual cut to happen 
variable_cut_fast_move_speed      : 100        # Speed mm/s
variable_cut_slow_move_speed      : 40        # Speed mm/s
variable_evacuate_speed           : 150       # Speed mm/s
variable_cut_dwell_time           : 50        # Time to dwell at the cut point in ms
variable_cut_fast_move_fraction   : 0.90      # Fraction of the move that uses fast move 0.0 - 1.0
variable_extruder_move_speed      : 25        # Speed mm/s for all extruder movement

# If the toolhead returns to initial position after the cut is complete.
variable_restore_position         : False     # True = return to initial position, False = don't return

# Distance to retract prior to making the cut, this reduces wasted filament but might cause clog 
# if set too large and/or if there are gaps in the hotend assembly 
# *This must be less than the distance from the nozzle to the cutter
variable_retract_length           : 33

# This can help prevent clogging of some toolheads by doing a quick tip from to reduce stringing
variable_quick_tip_forming        : False

# Number of times to run the cut movement
variable_cut_count                : 2

# Retract length and speed after the cut so that the cutter can go back 
# into its origin position
variable_rip_length               : 1.0       # Distance in mm to retract to aid lever decompression (>= 0)
variable_rip_speed                : 3         # Speed mm/s

# Pushback of the remaining tip from the cold end into the hotend
# *Must be less then retract_length
variable_pushback_length          : 25        # Distance in mm
variable_pushback_dwell_time      : 20        # Time to dwell between the pushback

# Safety margin for fast vs slow travel. When traveling to the pin location
# we make a safer but longer move if we are closer to the pin than this
# specified margin. Usually setting these to the size of the toolhead
# (plus a small margin) should be good enough 
variable_safe_margin_xy           : 20, 20    # Approx toolhead width +5mm, height +5mm)

# Some printers may need a boost of power to complete the cut without skipping steps.
# One option is to increase the current for the steppers in printer.cfg. Another
# option is to use these variables to set a current that is only used during the
# cut motion. Different combinations of kinematics and cutter configurations engage
# different combinations of steppers for that motion.  Set the needed variables.
# The override is skipped if the current is 0.

# Enable if layer shifts occur when cutting
# variable_cut_current_stepper_x: 0
# variable_cut_current_dual_carriage: 0  # This is the value that is used to define the current for the dual carriage stepper (2nd x) for an IDEX printer during the cut.
# variable_cut_current_stepper_y: 0
# variable_cut_current_stepper_z: 0

# Change these to match the entries in printer.cfg if needed
# variable_conf_name_stepper_x: "tmc2209 stepper_x"
# variable_conf_name_dual_carriage: "tmc2209 dual_carriage"
# variable_conf_name_stepper_y: "tmc2209 stepper_y"
# variable_conf_name_stepper_z: "tmc2209 stepper_z"
# variable_awd: True

# Addon variables for cutter pin servo control
#variable_tool_servo_enable        : False
#variable_tool_servo_name          : "tool_cut"
#variable_tool_servo_angle_out     : 115
#variable_tool_servo_angle_in      : 0

#--=================================================================================-
#------- Poop ----------------------------------------------------------------------
#--=================================================================================-
[gcode_macro _AFC_POOP_VARS]
description: Poop macro configuration variables
gcode: # Leave empty


variable_purge_loc_xy             : -50, 139    # (x,y) Location of where to purge
variable_purge_spd                : 3       # Speed, in mm/s, of the purge.
variable_z_purge_move             : True      # Set to False to not move in Z during poop

# Speed, in mm/s to lift z after the purge is completed. Its a faster lift to keep it from 
# sticking to the toolhead
variable_fast_z                   : 400
variable_z_lift                   : 30        # Z height to raise above the final purge position after the purge is completed as part of the fast z move
                                              # example: If final poop height ends at 20mm this variable will raise Z to 30mm

# If the toolhead returns to initial position after the poop is complete.
variable_restore_position         : False     # True = return to initial position, False = don't return

# The z height of the nozzle at the purge position before purging. This allows any built up
# pressure to escape before the purge.

variable_purge_start              : 0.5

# Set the part cooling fan speed. Disabling can help prevent the nozzle from cooling down 
# and stimulate flow, Enabling it can prevent blobs from sticking together.
variable_part_cooling_fan         : True      # Run it at full speed
variable_part_cooling_fan_speed   : 0.4       # Speed to run fan when enabled above. 0 - 1.0
variable_purge_cool_time          : 2         # Time to pause after purge to allow fan to cool the poop in seconds

# ==================== PURGE LENGTH TUNING
# Default purge length to fall back on when neither the tool map purge_volumes or 
# parameter PURGE_LENGTH is set.
variable_purge_length             : 72.111

# The absolute minimum to purge, even if you don't changed tools. This is to prime the 
# nozzle before printing
variable_purge_length_minimum     : 60.999

# The slicer values often are a bit too wasteful. Tune it here to get optimal values. 0.6
# is a good starting point.
#variable_purge_length_modifier    : 1
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

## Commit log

2025-05-15 Initial commit with full STLs, images, and RREADME guide
    Initial commit
    [Fan_Duct_Covers.stl, cpap_low_left.stl, cpap_low_right.stl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]
2025-05-15 Additional files
    [cutter_arm_mount_cutter_pin.stl, cutter_arm_mount_cutter_pin_long.stl, rear_pillar_brush_indexer.stl]
2025-05-27 Config files upload
    [AFC_Macro_Vars.cfg, printer.cfg, vendetta_led.cfg]
2025-09-29 Change 'Assembly Video' to 'Assembly Videos' Link
    Updated assembly video section to reflect production status.
2025-09-30 Upload BOM
    BOM with links added.
2025-09-30 Revise README for tools and BOM details
    Updated tools and materials section, added BOM link, and modified BOM section heading.
2025-10-01 BOM Upload
2025-10-01 BOM.md upload
2025-10-01 Fix BOM links in README.md
    Updated links to the Bill of Materials in README.
2025-10-01 Add assembly videos section to documentation
    Added a new section for assembly videos with links and descriptions.
2025-10-01 Update Assembly Videos section link in README
2025-10-02 Change quantity of M3x20 SHCS in BOM
    Updated quantity for M3x20 SHCS from 1 to 2.
2025-10-02 Add video link for Vendetta - Parts Assembly
    Added a new video link for 'Vendetta - Parts Assembly'.
2025-10-07 Update BOM links and prices for components
2025-10-07 Revise Bill of Materials with updated items
    Updated BOM with new links and prices.
2025-10-07 Revise Bill of Materials with updated details
    Updated BOM with new links and prices for components.
2025-10-07 Revise links and prices in BOM.md
    Updated links and prices for BOM items.
2025-10-07 Update link for MR63ZZ bearings in BOM.md
2025-10-07 Update link for Bamboo lab Filament Cutter Blade
2025-10-07 Update link for M3 Heat Inserts in BOM.md
2025-10-07 Revise links and prices in BOM.md
    Updated product links and prices for BOM items.
2025-10-07 Fix formatting in Bill of Materials table
2025-10-07 Fix line numbering in BOM.md
2026-06-05 Delete firmware/config_files/box_turtle_settings/AFC_Macro_Vars.cfg
    Delete stale AFC_Macros_Vars.cfg
    [AFC_Macro_Vars.cfg]
2026-06-05 Updated Box Turtle Settings
    Updated box turtle settings - For reference only.
    [AFC.cfg, AFC_Hardware.cfg, AFC_Macro_Vars.cfg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]
2026-10-04 Correct board to Octopus Pro v1.1 (H723) in BOM and README
